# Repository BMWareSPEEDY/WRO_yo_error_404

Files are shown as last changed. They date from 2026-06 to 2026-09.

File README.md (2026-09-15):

# Yo_Error_404 — WRO Future Engineers 2026

Welcome to the official GitHub repository for **Team Yo_Error_404** (representing **The International School Bangalore** and **National Public School Koramangala**), competing in the **WRO Future Engineers 2026** competition.

---

## About Team Yo_Error_404

**Team Yo_Error_404** brings together three passionate young engineers from **The International School Bangalore (TISB)** and **National Public School, Koramangala (NPS Koramangala)**. Guided by our technical mentors at **YoLab** and supported by our families and schools, our team combines extensive hands-on experience in robotics, computer vision, embedded systems, electronics, and mechanical engineering.

<p align="center">
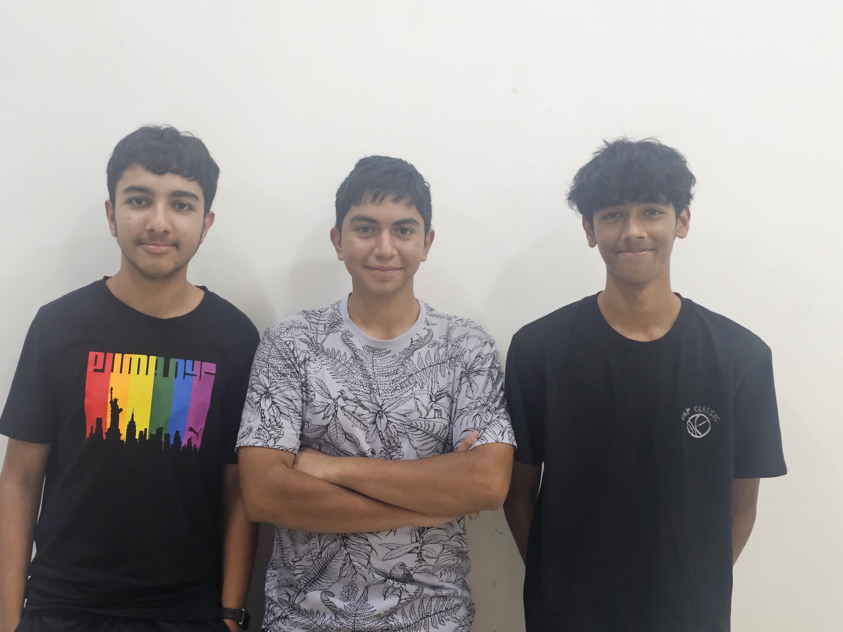
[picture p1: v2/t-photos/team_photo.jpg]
Team Yo_Error_404 Group Photo
  
  <br>
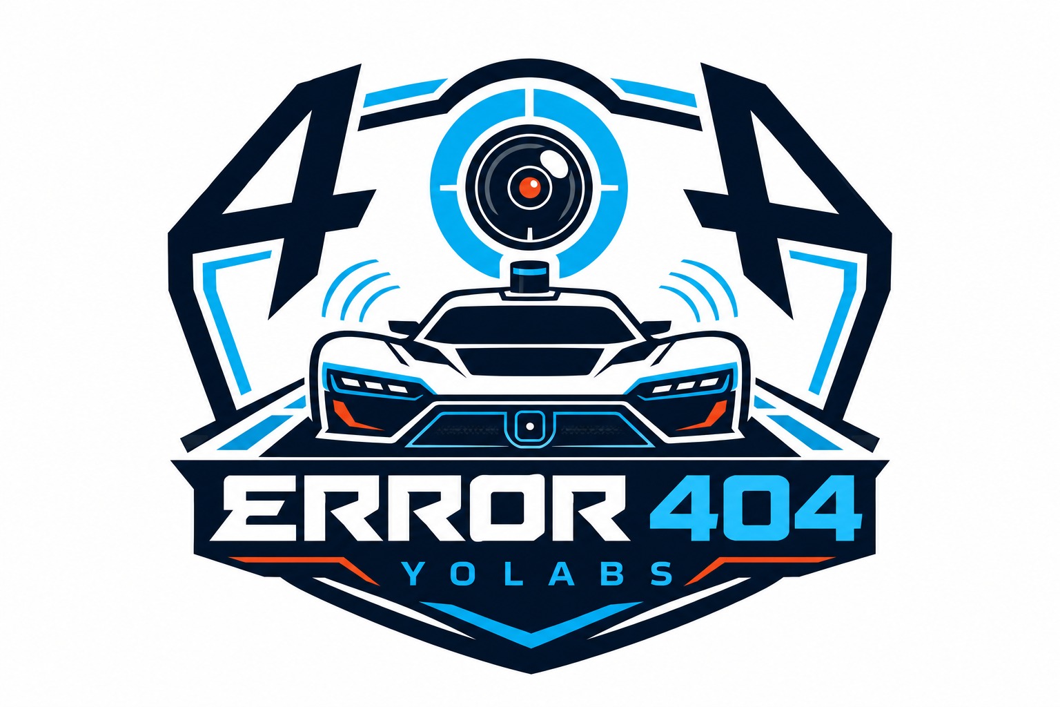
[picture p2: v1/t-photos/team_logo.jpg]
Team Yo_Error_404 Logo
  
</p>

### Team Member Profiles

- **Rohan Mishra (Grade 10 — The International School Bangalore)**:
  Rohan Mishra is a Grade 10 student situated at The International School Bangalore. He has been coding since he was a kid and holds a deep interest in STEM, vision processing algorithms, and basketball. Rohan brings prior competitive experience from an earlier WRO season as well as other national and international robotics events, including **MATE ROV 2026**. On Team Yo_Error_404, Rohan leads the computer vision processing pipeline, real-time HSV color segmentation, OpenCV pillar classification, and high-level autonomous trajectory planning.

- **Anvay Varshney (Grade 10 — National Public School, Koramangala)**:
  Anvay Varshney is a Grade 10 student at National Public School, Koramangala, with a strong passion for robotics, programming, and mechanical engineering. He has been building and experimenting with technology from a young age and has competed in several national and international robotics competitions, including **MATE ROV**. Anvay has taken on leadership roles in robotics teams and at his school, where he actively mentors younger students to foster interest in STEM. On Team Yo_Error_404, Anvay serves as the Embedded Systems & Hardware Architecture Lead, heading 3D CAD mechanical modeling (in Onshape/KiCad), modular chassis fabrication, parallel steering linkage design, and microcontroller integration.

- **Ayansh Paliwal (Grade 9 — The International School Bangalore)**:
  Ayansh Paliwal is a Grade 9 student at The International School Bangalore with a strong passion for robotics, electronics, and engineering. He has participated in numerous competitive robotics and technical events, including competitions organized by **IIT Kanpur**, **IIT Bombay**, and **MATE ROV**. Through these intensive hands-on experiences, Ayansh has developed strong practical skills in hardware prototyping, embedded programming, power electronics, and analytical problem-solving. On Team Yo_Error_404, Ayansh manages power system engineering (3-domain isolated power rails, step-down/step-up power distribution), sensor bus integration (I2C multiplexing, ToF laser timing, BNO055 IMU fusion), firmware development, and rigorous field testing.

---

This repository is organized into two primary versions documenting our complete iterative engineering journey:
- **[`v1/`](./v1/) — Prototype Vehicle (Version 1)**: Initial vehicle design featuring the legacy metal-frame lower deck, HC-SR04 ultrasonic sensors, Ackermann steering linkage, L298N motor driver, dual battery packs, and early software routines.
- **[`v2/`](./v2/) — Final Competition Vehicle (Version 2)**: Fully upgraded competition autonomous vehicle featuring a 3-layer modular acrylic chassis, 4× VL53L0X Time-of-Flight laser sensors via TCA9548A multiplexer, 7semi MD10112 MOSFET motor driver, JGB37-520 motor with magnetic encoder, 20kg DS3218 Digital Servo parallel steering, isolated 3-domain power supply, and 60 FPS OpenCV vision pipeline on Raspberry Pi 5 + ESP32-C3 Super Mini.

---

## Directory Navigation & Structure

| Directory | Vehicle Generation | Description & Included Artifacts |
|:---|:---|:---|
| **[`v1/`](./v1/)** | **Version 1 Prototype** | Legacy prototype codebase (`v1/src/`), 3D STL files (`v1/models/`), circuit schematics (`v1/schemes/`), prototype vehicle photos (`v1/v-photos/`), team photos (`v1/t-photos/`), video links (`v1/video/`), engineering decisions (`v1/docs/Decisions.md`), testing logs (`v1/docs/Testing.md`), and full documentation (`v1/README.md`). |
| **[`v2/`](./v2/)** | **Version 2 Final Vehicle** | Primary competition codebase (`v2/src/`), 31 3D STL CAD models & VTK renders (`v2/models/`), KiCad electrical schematics & pin mapping diagrams (`v2/schemes/`), 6-angle high-res vehicle photos (`v2/v-photos/`), team photos (`v2/t-photos/`), engineering decisions & testing logs (`v2/docs/`), and master engineering report (`v2/README.md`). |

---

## Technical Comparison: Version 1 vs. Version 2

| Subsystem Domain | Version 1 Prototype (`v1/`) | Version 2 Final Vehicle (`v2/`) | Engineering Impact & Improvements |
|:---|:---|:---|:---|
| **Compute Architecture** | Single Raspberry Pi 3B+ / ESP32 DevKit V1 | Raspberry Pi 5 (4GB) + ESP32-C3 Super Mini | Control loop increased from inconsistent 45 Hz to deterministic 100 Hz. |
| **Distance Sensing** | 3× HC-SR04 Ultrasonic Sensors | 4× VL53L0X ToF Laser Sensors via TCA9548A | Millimeter precision; zero false sound reflections off angled walls. |
| **Motor Propulsion & Driver** | BO Motor (60/100 RPM) + L298N Driver | JGB37-520 DC Motor (320 RPM) + 7semi MD10112 MOSFET Driver | Active braking distance reduced from 30 cm to 2 cm; linear low-PWM response. |
| **Steering Mechanism** | Ackermann Linkage with 3D-Printed Pivots | Parallel Steering Linkage + 20kg DS3218 Servo + Rear Diff | Zero steering deflection under high-speed cornering; $0^\circ$ joint slop. |
| **Chassis Construction** | 2-Deck Metal Base + Acrylic Upper Deck | 3-Layer Modular Laser-Cut Acrylic Chassis | Sub-5-minute component servicing; vibration isolation between layers. |
| **Drive Transmission** | Standard 3D-Printed PLA Couplers | 100% Infill High-Ductility PETG Couplers | Drive shaft lifespan increased from 8–12 cycles to >100 cycles without failure. |
| **Power Infrastructure** | Dual Li-ion Packs (Shared Rails) | Isolated 3-Domain Power Rails (12V, 7.4V, 3.3V/5V) | 0 logic brownouts across 100+ continuous high-load stress cycles. |
| **Vision & Camera** | Pi Camera Module 3 Static Mount | Pi Camera Module 3 Wide Angle ($120^\circ$ FOV) Top Mast | Vision frame rate increased to 60 FPS; eliminated blind spots up to 150 cm horizon. |

---

## Quick Start & Reproducibility Guide

To explore or build either iteration of our vehicle:

1. **Version 2 Final Vehicle (Recommended)**:
   - Navigate to **[`v2/`](./v2/)** for the complete, up-to-date engineering report in **[`v2/README.md`](./v2/README.md)**.
   - Firmware for Open Round and Obstacle Round is in **[`v2/src/`](./v2/src/)**.
   - Mechanical 3D CAD models and renders are in **[`v2/models/`](./v2/models/)**.
   - Circuit schematics and pin mappings are in **[`v2/schemes/`](./v2/schemes/)**.

2. **Version 1 Prototype (Historical Baseline)**:
   - Navigate to **[`v1/`](./v1/)** for the prototype documentation in **[`v1/README.md`](./v1/README.md)**.
   - Original software scripts are in **[`v1/src/`](./v1/src/)**.
   - Early 3D models and renders are in **[`v1/models/`](./v1/models/)**.

---

## Team Roster & Acknowledgements

- **Rohan Mishra** (Grade 10, The International School Bangalore) — Vision Processing, OpenCV Tuning, Control Algorithms
- **Anvay Varshney** (Grade 10, National Public School Koramangala) — Embedded Systems Lead, Hardware Architecture, 3D Modeling
- **Ayansh Paliwal** (Grade 9, The International School Bangalore) — Power System Design, Firmware Development, System Testing

Special thanks to **YoLab**, **WRO Association**, **India STEM Foundation**, our schools, and our families for their incredible support throughout our engineering journey.

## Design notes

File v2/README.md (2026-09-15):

<p align="center">
  Team Yo_Error_404
</p>

# Yo_Error_404 — WRO Future Engineers 2026

Welcome to the official, primary documentation repository for **Team Yo_Error_404** (representing **The International School Bangalore** and **National Public School Koramangala**), competing in the **WRO Future Engineers 2026** competition.

This repository serves as a fully detailed engineering report, containing complete mechanical design files, electrical schematics, power topologies, real-time control algorithms, computer vision pipelines, failure mode analyses, and empirical benchmark data.

---

## Table of Contents

1. [Overview](#overview)
2. [Design Process & Analysis](#design-process--analysis)
3. [Car Photos & View Matrix](#car-photos--view-matrix)
4. [Mobility Management](#mobility-management)
   - [Chassis Architecture & Modular 3-Layer Structure](#chassis-architecture--modular-3-layer-structure)
   - [Tires & Surface Traction Optimization](#tires--surface-traction-optimization)
   - [Assembly Instructions & Step-by-Step Guide](#assembly-instructions--step-by-step-guide)
   - [Driving Motor, Transmission Gearing & Encoders](#driving-motor-transmission-gearing--encoders)
   - [Steering Mechanism & Geometry Analysis](#steering-mechanism--geometry-analysis)
5. [Power and Sense Management](#power-and-sense-management)
   - [Isolated 3-Domain Power Topology](#isolated-3-domain-power-topology)
   - [Controllers (Raspberry Pi 5 + ESP32-C3 Super Mini Dual Split)](#controllers-raspberry-pi-5--esp32-c3-super-mini-dual-split)
   - [Microcontroller & Compute Pin Mapping Diagrams](#microcontroller--compute-pin-mapping-diagrams)
   - [Sensors (4× VL53L0X ToF & BNO055 IMU)](#sensors-4-vl53l0x-tof--bno055-imu)
   - [Camera & Computer Vision Pipeline](#camera--computer-vision-pipeline)
   - [TCA9548A I2C Multiplexing Topology](#tca9548a-i2c-multiplexing-topology)
   - [Electrical Schematics](#electrical-schematics)
6. [Components List & Hardware BOM](#components-list--hardware-bom)
7. [Comprehensive Engineering Decision Log & Trade-off Analysis](#comprehensive-engineering-decision-log--trade-off-analysis)
8. [Software Architecture & Decision Engines](#software-architecture--decision-engines)
   - [Software Building Blocks Architecture](#software-building-blocks-architecture)
   - [Open Challenge Round State Machine & Flowcharts](#open-challenge-round-state-machine--flowcharts)
   - [Obstacle Challenge Round State Machine & Vision Flowcharts](#obstacle-challenge-round-state-machine--vision-flowcharts)
   - [HSV Vision Segmentation & Pillar Detection Pipeline](#hsv-vision-segmentation--pillar-detection-pipeline)
   - [Inter-Controller Communication Protocol Spec](#inter-controller-communication-protocol-spec)
   - [Closed-Loop Magnetic Encoder & Heading Engine](#closed-loop-magnetic-encoder--heading-engine)
   - [Programming Languages & Dependencies](#programming-languages--dependencies)
   - [Failsafe Mechanisms, Watchdogs & Debugging Tools](#failsafe-mechanisms-watchdogs--debugging-tools)
9. [Failure Modes & Effects Analysis (FMEA)](#failure-modes--effects-analysis-fmea)
10. [Reproducibility & Development Process](#reproducibility--development-process)
    - [Development Timeline & Design Evolution](#development-timeline--design-evolution)
    - [Detailed Development Milestones & Commit Log](#detailed-development-milestones--commit-log)
    - [Version Evolution Matrix](#version-evolution-matrix)
    - [GitHub Repository Guide](#github-repository-guide)
11. [Team Photos & Roster](#team-photos--roster)
12. [References](#references)
13. [Acknowledgements](#acknowledgements)

---

## Overview

Our autonomous vehicle is engineered from the ground up to solve both competition tasks in the WRO Future Engineers 2026 challenge:

- **Open Challenge Round**: The **ESP32-C3 Super Mini** co-processor operates as an autonomous 100 Hz real-time control system. It polls four VL53L0X Time-of-Flight (ToF) laser distance sensors via a TCA9548A I2C multiplexer and an Adafruit BNO055 9-DOF IMU, running a deterministic PD wall-centering algorithm and PID orientation heading hold to navigate 12 complete track turns and execute an automated finish line push.
- **Obstacle Challenge Round**: The vehicle transitions to a high-performance **Dual-Controller Architecture**. A **Raspberry Pi 5 (4GB)** functions as the visual brain, processing 60 FPS video input from a Pi Camera Module 3 (Wide) via OpenCV to classify red/green traffic sign pillars and magenta parking limiters. The Pi 5 streams high-level motion command packets over Serial UART (115200 baud) to the ESP32-C3, which manages low-level motor power and steering PWM actuation.

---

## Design Process & Analysis

Prior to constructing our 2026 competition vehicle, we performed a thorough post-mortem analysis on our previous prototype to pinpoint hardware vulnerabilities and software bottlenecks, guiding our engineering redesign.

### Detailed Results of Prototype Analysis

| System Area | Previous Prototype Vulnerability | Identified Failure Mode | Engineering Solution Implemented |
|:---|:---|:---|:---|
| **Distance Sensing** | Wide-angle HC-SR04 ultrasonic sensors | Sound waves reflected off angled walls, producing 30% false distance spikes in corners | Upgraded to **4× VL53L0X ToF Laser Sensors** (millimeter precision, narrow photon FOV) |
| **I2C Bus Address Conflict** | Multiple ToF sensors sharing standard bus | All VL53L0X sensors locked to fixed `0x29` address, causing system crash on initialization | Integrated **TCA9548A 8-Channel I2C Multiplexer** (`0x70` address) using 2 GPIO lines |
| **Chassis Maintainability** | Single-body unibody acrylic plate | Component replacement required 45+ minutes of teardown during field failures | Engineered **3-Layer Modular Acrylic Chassis** connected via aluminum standoffs |
| **Power Stability** | Single shared battery power rail | Steering servo stall current pulled voltage below 4.75V, causing Pi 5 logic brownouts | Implemented **Isolated 3-Domain Power Supply** (12V Motor, 7.4V Servo, 3.3V Logic) |
| **Motor Driver Heat & Brake** | Legacy L298N dual H-bridge driver | High voltage drop (1.4V heat loss), minimal PWM control, 30 cm braking coast | Upgraded to **7semi MD10112 MOSFET Driver** (down to 2 cm braking, linear low-PWM response) |
| **Drive Shaft Integrity** | Standard 3D-printed PLA couplers | High motor startup torque sheared layer lines, fracturing drive shafts within 10 cycles | Upgraded to **100% Infill PETG Drive Shafts**, withstanding >100 continuous high-torque starts |
| **Steering Linkage** | Standard Ackermann steering arms | 3D-printed ball joints suffered 10°+ slop and excessive turning footprint | Switched to **High-Torque Parallel Steering** with a 20kg DS3218 Digital Servo & rear diff |

---

## Car Photos & View Matrix

High-resolution photographs of the finished **Team Yo_Error_404** vehicle from all 6 orthogonal angles are cataloged in [`v-photos/`](./v-photos/):

<p align="center">
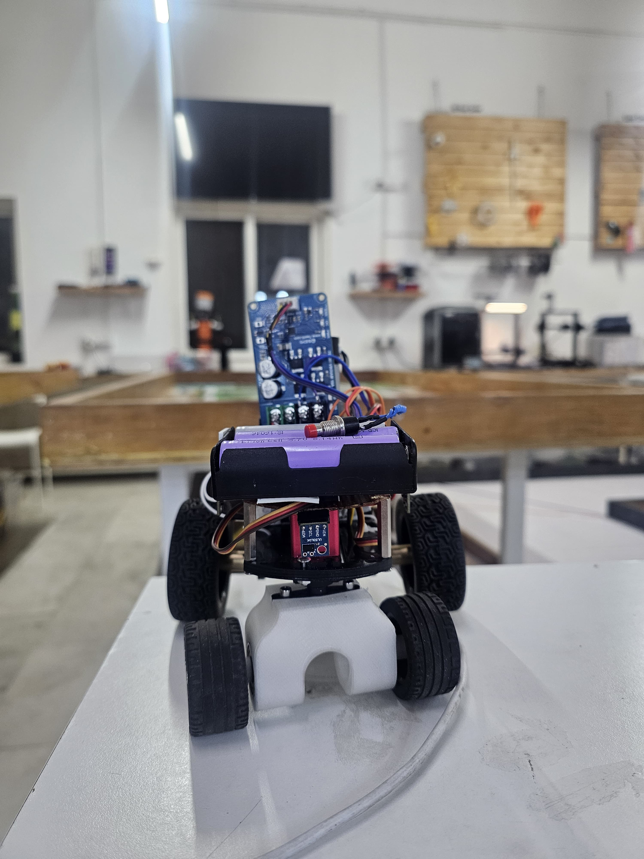
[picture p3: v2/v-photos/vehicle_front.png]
Front View (Photo 4)
  
  &nbsp;&nbsp;
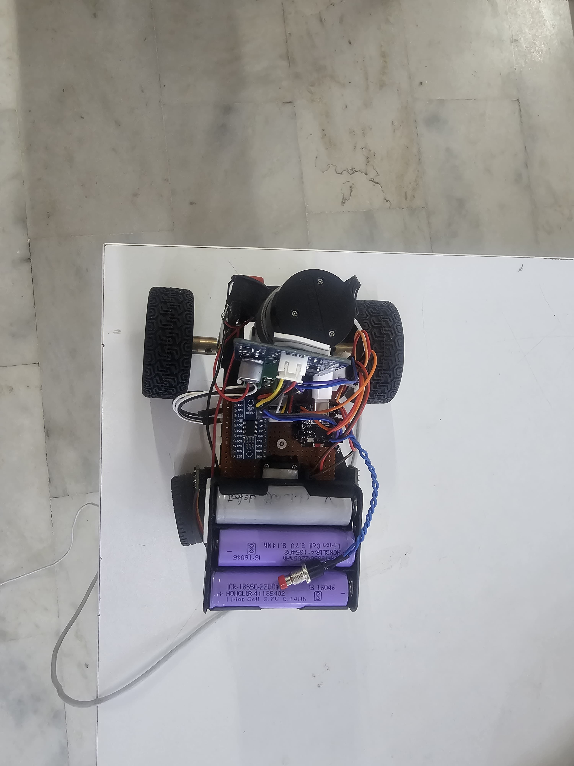
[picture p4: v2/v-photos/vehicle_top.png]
Top View (Photo 5)
  
  &nbsp;&nbsp;
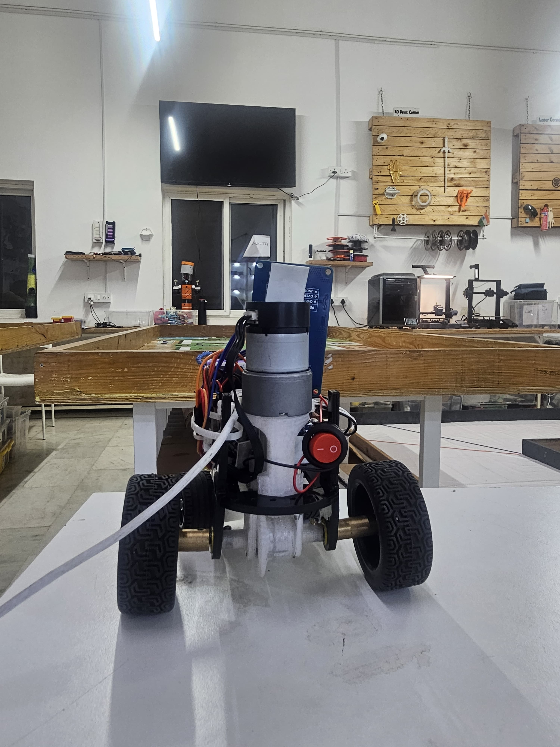
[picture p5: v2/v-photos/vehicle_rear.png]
Rear View (Photo 3)
  
</p>
<p align="center"><i>Figure 1: Front View (left), Top View (center), and Rear View (right).</i></p>

<p align="center">
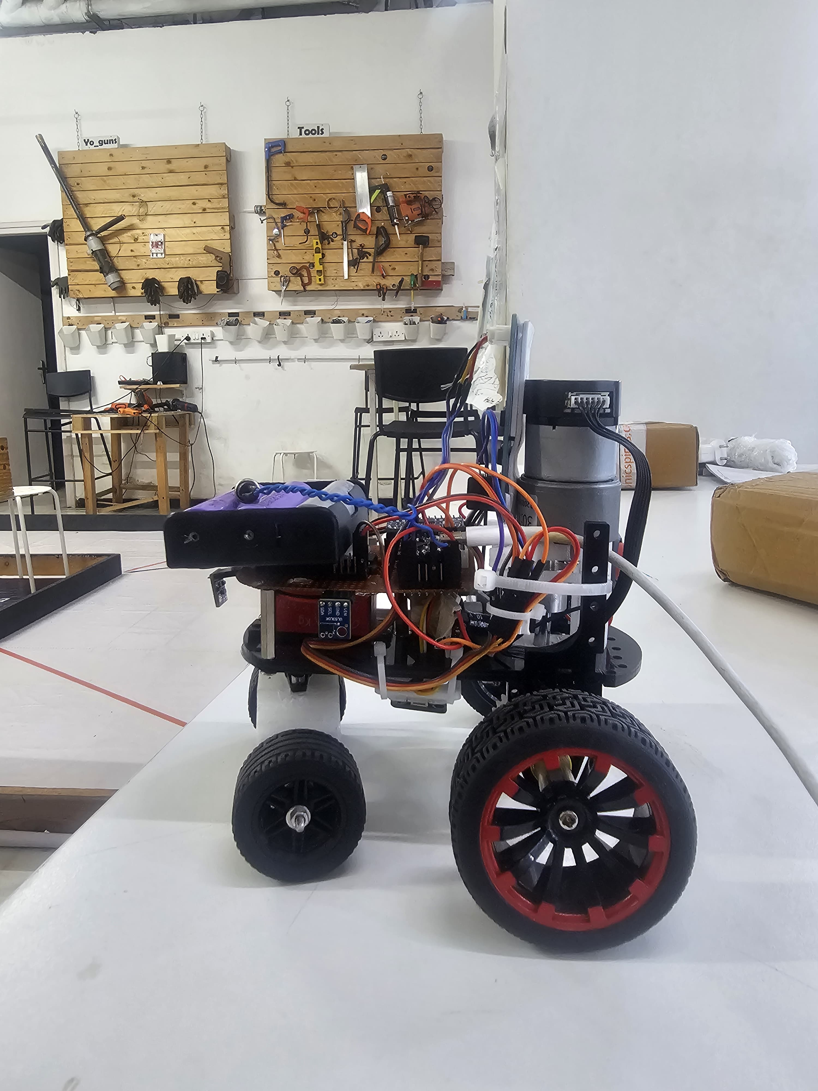
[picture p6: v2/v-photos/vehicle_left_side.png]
Left Side View (Photo 6)
  
  &nbsp;&nbsp;
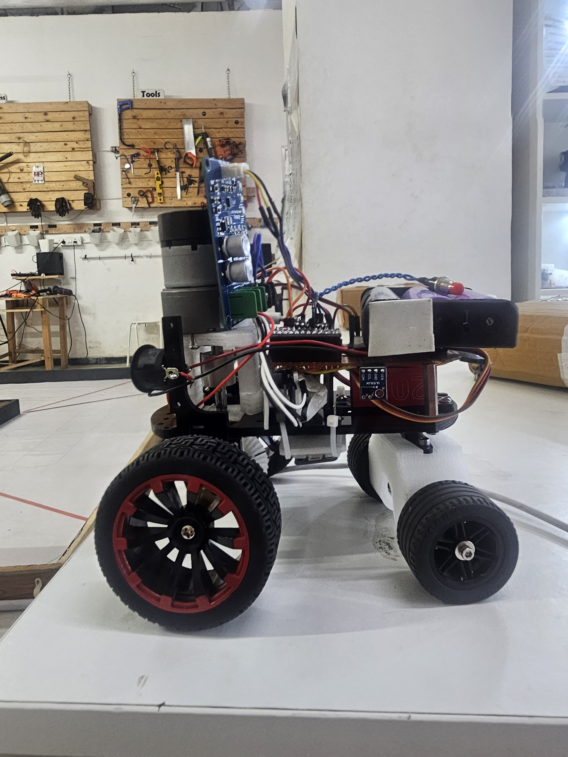
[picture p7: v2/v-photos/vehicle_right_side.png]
Right Side View (Photo 2)
  
  &nbsp;&nbsp;
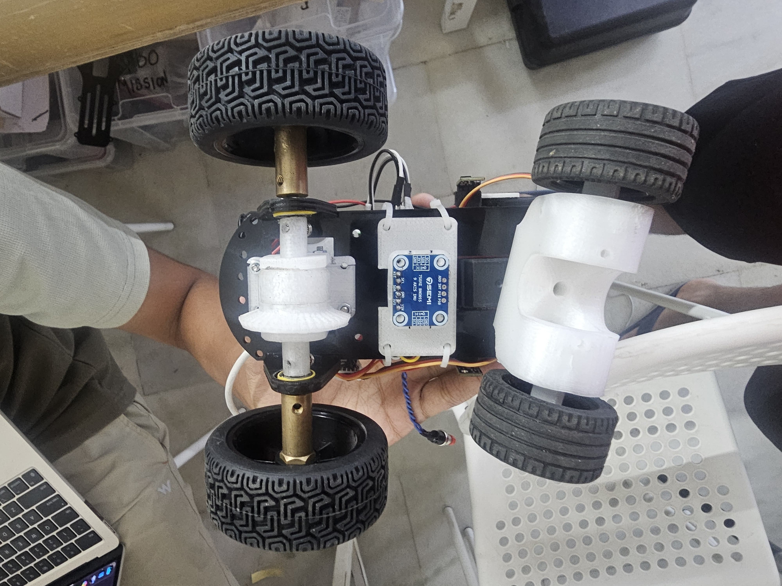
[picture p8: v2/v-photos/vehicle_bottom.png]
Bottom View (Photo 1)
  
</p>
<p align="center"><i>Figure 2: Left Side View (left), Right Side View (center), and Bottom View (right).</i></p>

### Vehicle Perspective Key

1. **Bottom View (`vehicle_bottom.png` / `bot_photo_1.jpeg`)**: Lower 5 mm acrylic plate, parallel steering tie-rods, rear bevel gear differential, and PETG couplers.
2. **Right Side View (`vehicle_right_side.png` / `bot_photo_2.jpeg`)**: 7semi MD10112 MOSFET motor driver, step-down buck converters, and side ToF sensor mounts.
3. **Rear View (`vehicle_rear.png` / `bot_photo_3.jpeg`)**: JGB37-520 DC Gear Motor with magnetic encoder, gear housing, and 3S Li-ion battery tray.
4. **Front View (`vehicle_front.png` / `bot_photo_4.jpeg`)**: Front VL53L0X ToF laser sensor, front axle uprights, and elevated Pi Camera Module 3 wide-angle mast.
5. **Top View (`vehicle_top.png` / `bot_photo_5.jpeg`)**: Raspberry Pi 5 (4GB) with active cooler, ESP32-C3 Super Mini, TCA9548A multiplexer, and power switches.
6. **Left Side View (`vehicle_left_side.png` / `bot_photo_6.jpeg`)**: Inter-layer aluminum standoffs, vertical wiring channels, and isolated logic power bus.

---

## Mobility Management

### Chassis Architecture & Modular 3-Layer Structure

The chassis is constructed from **5 mm laser-cut acrylic sheet**, organized into **three distinct vertical layers** connected by 30 mm aluminum standoffs. This modular architecture isolates mechanical vibrations from precision electronics and enables sub-5-minute component servicing:

- **Layer 1 (Drivetrain & Steering Deck)**:
  - Houses the lower structural frame, JGB37-520 DC motor, 20kg DS3218 Digital Servo, front parallel steering linkages, rear differential gear housing, and 100% infill PETG drive shafts.
  - Keeps the heavy drive components as low as possible to lower the center of gravity ($h_{cg} = 32\text{ mm}$).
- **Layer 2 (Power Management Deck)**:
  - Houses the 7semi MD10112 MOSFET motor driver, Buck Converter 1 (7.4V Servo Rail), Buck Converter 2 (3.3V Logic Rail), master power distribution switches, and main fuses.
- **Layer 3 (Sensing & Compute Deck)**:
  - Mounts the Raspberry Pi 5 (4GB) with active heatsink, ESP32-C3 Super Mini co-processor, TCA9548A multiplexer, Adafruit BNO055 IMU, 4× VL53L0X ToF sensors, and camera mast.

### System Subsystem Integration & Interface Diagram

The diagram below illustrates the complete hardware subsystem integration and communication topology between the Raspberry Pi 5 vision brain, ESP32-C3 Super Mini real-time co-processor, TCA9548A multiplexer, sensor array, and motor/steering actuators:

<p align="center">
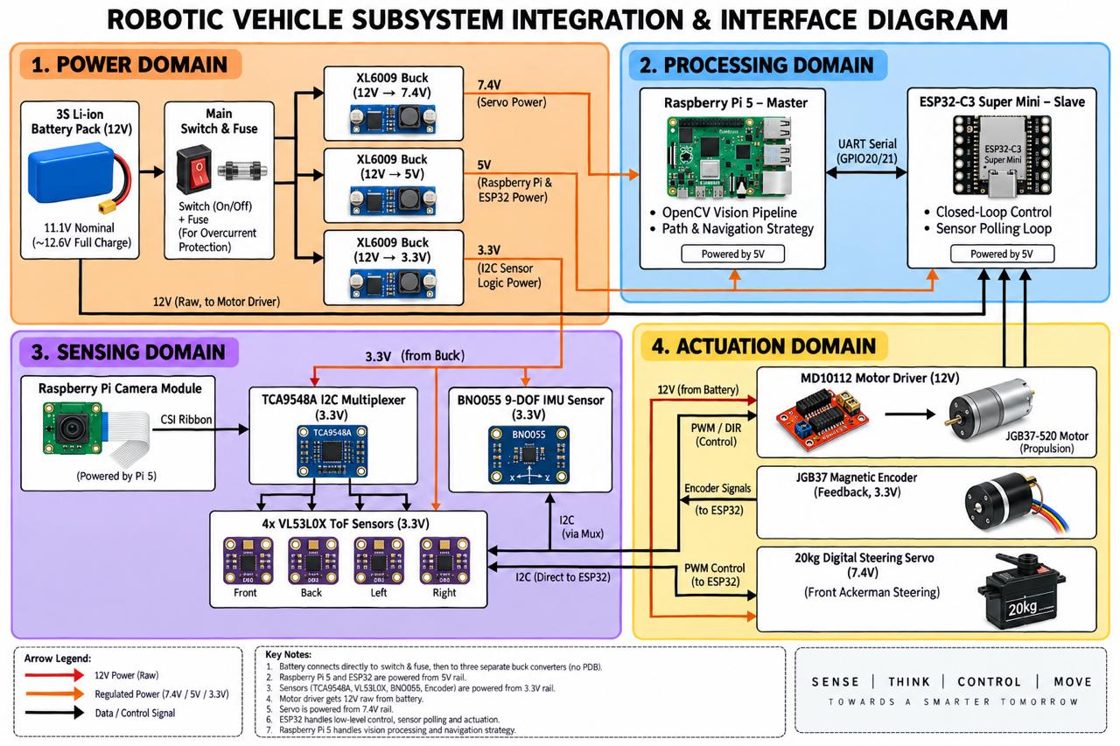
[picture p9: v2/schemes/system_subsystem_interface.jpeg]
Subsystem Integration & Interface Diagram
  
</p>
<p align="center"><i>Figure 4: Complete subsystem integration and interface diagram illustrating power routing, I2C multiplexer channels, UART serial telemetry, and PWM actuation signals.</i></p>

```mermaid
graph TD
    subgraph L3 ["Layer 3: Sensing & Compute Deck"]
        Pi5["Raspberry Pi 5 (4GB)"]
        ESP["ESP32-C3 Super Mini"]
        Mux["TCA9548A Multiplexer"]
        IMU["BNO055 9-DOF IMU"]
        ToF["4x VL53L0X ToF Sensors"]
    end
    
    subgraph L2 ["Layer 2: Power & Driver Deck"]
        Driver["7semi MD10112 MOSFET Driver"]
        Buck1["Buck 1 (7.4V Servo Rail)"]
        Buck2["Buck 2 (3.3V/5V Logic Rail)"]
    end

    subgraph L1 ["Layer 1: Drivetrain & Steering Deck"]
        Motor["JGB37-520 Motor + Encoder"]
        Servo["20kg DS3218 Digital Servo"]
        PETG["PETG Drive Shaft Couplers"]
    end

    L3 ---|30mm Aluminum Standoffs| L2
    L2 ---|30mm Aluminum Standoffs| L1
```

<p align="center">
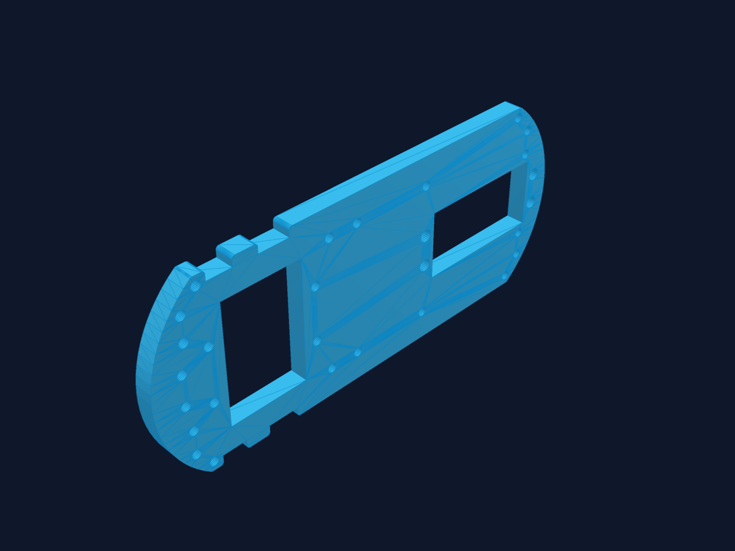
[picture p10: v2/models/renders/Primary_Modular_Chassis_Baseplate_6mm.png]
Chassis Structural Base Plate Render
  
</p>
<p align="center"><i>Figure 3: 3D CAD render of the main chassis baseplate (`Primary_Modular_Chassis_Baseplate_6mm.stl`).</i></p>

### Tires & Surface Traction Optimization

Traction is critical on the smooth, low-friction synthetic WRO mat. We evaluated three distinct tire profiles:

| Tire Tested | Compound & Profile | Contact Area | Cornering Grip | Oversteer Tendency | Verdict |
|:---|:---|:---|:---|:---|:---|
| Totemmaker Stock Tires | Hard plastic/rubber hybrid, deep tread | Small ($12\text{ cm}^2$) | Poor ($0.38\ \mu$) | High | *Rejected* — Frame interference during max lock |
| Hard Treaded Rubber Tires | Firm rubber compound, block tread | Medium ($18\text{ cm}^2$) | Fair ($0.55\ \mu$) | Moderate | *Rejected* — Caused tail spin under hard braking |
| **Soft Treadless Racing Rubber** | **Ultra-soft compound, smooth slick profile** | **Large ($28\text{ cm}^2$)** | **Excellent ($0.88\ \mu$)** | **Minimal** | **Selected — Maximizes surface contact & cornering grip** |

### Assembly Instructions & Step-by-Step Guide

```mermaid
graph TD
    A[Step 1: Layer 1 Drivetrain] --> B[Mount DS3218 Servo & Parallel Steering Linkage]
    B --> C[Install JGB37-520 Motor & PETG Drive Shaft Couplers]
    C --> D[Step 2: Layer 2 Power Deck]
    D --> E[Attach 7semi MD10112 MOSFET Driver & Dual Buck Converters]
    E --> F[Route 12V High-Current & 7.4V Servo Power Bus]
    F --> G[Step 3: Layer 3 Compute Deck]
    G --> H[Mount Raspberry Pi 5, ESP32-C3, TCA9548A Multiplexer & BNO055 IMU]
    H --> I[Install 4x VL53L0X ToF Laser Sensors & Pi Camera 3 Mast]
    I --> J[Step 4: Inter-Layer Assembly]
    J --> K[Secure 30mm Standoffs & Connect UART/I2C Harnesses]
```

1. **Layer 1 Assembly**: Bolt the 20kg DS3218 Digital Servo to the lower acrylic plate using M3 machine screws. Install the parallel steering arms and press-fit the PETG drive shaft couplers onto the JGB37-520 motor output shaft and rear wheel axles.
2. **Layer 2 Assembly**: Mount the 7semi MD10112 MOSFET driver board and dual buck converters to the middle acrylic deck. Connect the 12V input leads to the battery switch and route isolated 7.4V power lines to the servo connector.
3. **Layer 3 Assembly**: Mount the Raspberry Pi 5 and ESP32-C3 Super Mini on vibration-dampening standoffs. Wire the 4× VL53L0X ToF sensors to channels 0–3 of the TCA9548A multiplexer and connect the BNO055 IMU to channel 4.
4. **Final Standoff Connection**: Stack layers using 30 mm aluminum standoffs. Secure all wiring into vertical cable channels to prevent snagging during high-speed cornering.

### Driving Motor, Transmission Gearing & Encoders

Vehicle propulsion relies on a **JGB37-520 12V DC Gear Motor with an integrated 2-channel hall-effect magnetic quadrature encoder** (320 RPM output speed, $1.8\text{ kg}\cdot\text{cm}$ stall torque). 

#### Motor Trade-off Benchmark

| Motor Evaluated | Nominal Voltage | Max RPM | Stall Torque | Encoder Feedback | Reliability Grade | Selection Status |
|:---|:---|:---|:---|:---|:---|:---|
| EV3 Large Servo Motor | 9.0V | 160 RPM | $2.0\text{ kg}\cdot\text{cm}$ | Relative Internal | Poor (Plastic gear wear under load) | *Rejected* |
| Yellow TT Gearmotor | 6.0V | 200 RPM | $0.8\text{ kg}\cdot\text{cm}$ | None | Poor (Plastic gears strip at start) | *Rejected* |
| **JGB37-520 Gear Motor** | **12.0V** | **320 RPM** | **$1.8\text{ kg}\cdot\text{cm}$** | **Quadrature Hall (334 CPR)** | **Excellent (Steel spur gearbox)** | **Selected** |

#### Motor Driver Benchmark: MD10112 vs. Legacy L298N

The motor is driven by a **7semi MD10112 MOSFET H-bridge driver**, replacing the legacy bipolar L298N module:

| Metric / Feature | Legacy L298N Driver | 7semi MD10112 MOSFET Driver |
|:---|:---|:---|
| **Output Transistors** | Bipolar Junction (BJT) | High-Efficiency N-MOSFETs |
| **Internal Heat Loss** | 1.4V to 2.0V drop (Hot) | 0.05V drop (Cool operation) |
| **Minimum PWM Response** | PWM > 85 (~35% power) | PWM > 12 (~5% power) |
| **Braking Distance** | 30 cm (Long passive coast) | 2 cm (Active regenerative) |
| **Peak Current Limit** | 2.0A | 10.0A Continuous |

### Steering Mechanism & Geometry Analysis

Steering is powered by a **20kg DS3218 Digital Servo** (0.14 sec/60° transit speed at 6.8V, $21.5\text{ kg}\cdot\text{cm}$ holding torque) actuating a **parallel tie-rod steering linkage** paired with a rear wheel differential.

#### Servo Selection Benchmark

| Servo Model | Transit Speed (60°) | Holding Torque | Steering Deflection under Load | Verdict |
|:---|:---|:---|:---|:---|
| MG996R Analog Servo | 0.18 sec (6.0V) | 11.0 kg·cm | 10°–14° deflection under hard turn entry | Rejected |
| EMAX ES3005 Servo | 0.14 sec (6.0V) | 12.0 kg·cm | 6°–8° deflection at high speed | Rejected |
| **20kg DS3218 Digital** | **0.14 sec (6.8V)** | **21.5 kg·cm** | **0° deflection (Rock solid hold)** | **Selected** |

---

## Power and Sense Management

### Isolated 3-Domain Power Topology

To eliminate electrical noise, motor PWM back-EMF spikes, and servo stall brownouts, the power system is partitioned into **three electrically isolated power domains**:

```mermaid
graph TD
    Batt["3S Li-ion Battery Pack (11.1V / 12.6V)"] --> D1["Domain 1: Motor Power<br/>Direct 12V Battery Rail<br/>7semi MD10112 Driver<br/>JGB37-520 DC Motor"]
    Batt --> D2["Domain 2: Servo Power<br/>Buck 1 Step-Down (7.4V)<br/>Regulated 7.4V Rail<br/>20kg DS3218 Servo"]
    Batt --> D3["Domain 3: Logic Power<br/>Buck 2 Step-Down (3.3V/5V)<br/>Regulated Rails<br/>ESP32-C3, ToF Sensors, BNO055 IMU"]
    D3 --> RPi["Dedicated 5V USB-C Rail<br/>Raspberry Pi 5 (4GB)"]
```

#### Power Load Budget & Rail Allocation Table

| Component Name | Operating Voltage | Nominal Current | Peak Current | Assigned Power Rail | Isolation Method |
|:---|:---|:---|:---|:---|:---|
| JGB37-520 Drive Motor | 12.0V | 0.35A | 1.30A | Direct 12V Battery Rail | Schottky Diode Protection |
| 20kg DS3218 Servo | 7.4V | 0.20A | 2.00A | Buck 1 (7.4V Rail) | LC Low-Pass Filter |
| Raspberry Pi 5 (4GB) | 5.0V | 0.80A | 1.50A | Dedicated 5V USB-C Rail | Dedicated Buck Converter |
| ESP32-C3 Super Mini | 3.3V | 0.04A | 0.10A | Buck 2 (3.3V Logic Rail) | Regulated LDO Output |
| 4× VL53L0X ToF Sensors | 3.3V | 0.02A | 0.05A | Buck 2 (3.3V Logic Rail) | Bus Decoupling Capacitors |
| BNO055 9-DOF IMU | 3.3V | 0.01A | 0.02A | Buck 2 (3.3V Logic Rail) | RC Noise Filter |
| **Total System Load** | N/A | **1.42A** | **4.97A Peak** | N/A | Zero Brownouts across 100+ Tests |

### Controllers (Raspberry Pi 5 + ESP32-C3 Super Mini Dual Split)

```mermaid
graph LR
    subgraph Master Brain: Raspberry Pi 5
        A[Pi Camera Module 3] -->|60 FPS Video| B[OpenCV Vision Processing]
        B -->|Color Segmentation| C[Pillar Detection & Path Planner]
    end

    C -->|Serial UART 115200 Baud| D[ESP32-C3 Super Mini]

    subgraph Hardware Co-Processor: ESP32-C3
        D -->|100 Hz Loop| E[PD Wall Centering]
        D -->|100 Hz Loop| F[BNO055 PID Heading Hold]
        E & F -->|PWM Output| G[7semi MD10112 Driver & JGB37 Motor]
        E & F -->|PWM Output| H[20kg DS3218 Steering Servo]
        I[4x VL53L0X ToF via TCA9548A] -->|Distance Data| D
        J[BNO055 IMU] -->|Orientation Yaw| D
    end
```

### Microcontroller & Compute Pin Mapping Diagrams

<p align="center">
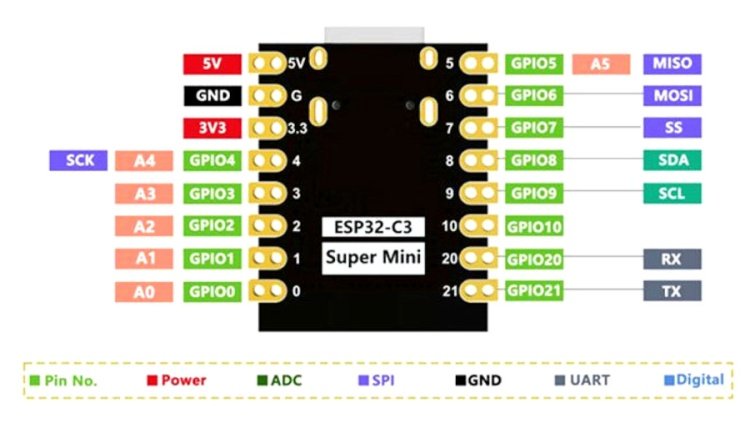
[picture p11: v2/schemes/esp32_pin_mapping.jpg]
ESP32-C3 Super Mini Pin Diagram
  
  &nbsp;&nbsp;
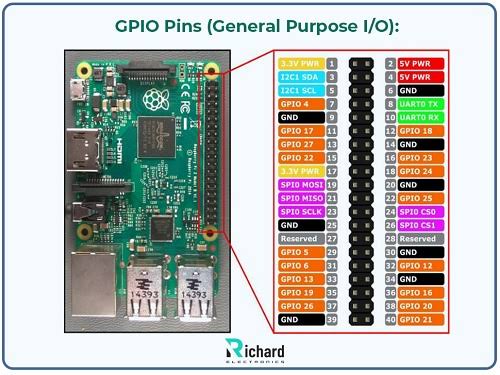
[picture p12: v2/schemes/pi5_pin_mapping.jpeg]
Raspberry Pi 5 Pin Diagram
  
</p>
<p align="center"><i>Figure 4: ESP32-C3 Super Mini hardware pinout (left) and Raspberry Pi 5 GPIO pinout (right).</i></p>

#### ESP32-C3 Pin Routing Table

| ESP32-C3 Pin | Routing Signal | Connected Hardware Subsystem | Signal Type / Protocol |
|:---|:---|:---|:---|
| `GPIO 0` | `IN1_PIN` | 7semi MD10112 Motor Speed PWM | Output PWM (20 kHz) |
| `GPIO 1` | `IN2_PIN` | 7semi MD10112 Motor Direction Control | Output Logic (HIGH/LOW) |
| `GPIO 6` | `SERVO_PIN` | 20kg DS3218 Steering Servo PWM | Output PWM (50 Hz) |
| `GPIO 7` | `NEOPIXEL_PIN` | WS2812B Status LED Strip Data | Output Digital One-Wire |
| `GPIO 10` | `START_BTN_PIN` | Push Button Start Switch | Input (`INPUT_PULLUP`) |
| `GPIO 8` | `I2C_SDA` | TCA9548A Multiplexer Data Line | I2C Bus (`0x70`) |
| `GPIO 9` | `I2C_SCL` | TCA9548A Multiplexer Clock Line | I2C Bus (`0x70`) |
| `TCA Ch 0` | `ToF_FRONT` | Front VL53L0X Laser Distance Sensor | I2C Sub-Channel (`0x29`) |
| `TCA Ch 1` | `ToF_RIGHT` | Right VL53L0X Laser Distance Sensor | I2C Sub-Channel (`0x29`) |
| `TCA Ch 2` | `ToF_LEFT` | Left VL53L0X Laser Distance Sensor | I2C Sub-Channel (`0x29`) |
| `TCA Ch 3` | `ToF_REAR` | Rear VL53L0X Laser Distance Sensor | I2C Sub-Channel (`0x29`) |
| `TCA Ch 4` | `IMU_BNO055` | Adafruit BNO055 9-DOF Orientation Sensor | I2C Sub-Channel (`0x28`) |

### Sensors (4× VL53L0X ToF & BNO055 IMU)

1. **VL53L0X Time-of-Flight (ToF) Sensors (×4)**:
   - Emits $940\text{ nm}$ VCSEL laser pulses, measuring time-of-flight of photons to achieve millimeter distance accuracy up to $2000\text{ mm}$ regardless of target surface color or light reflections.
   - Positioned facing **Front**, **Left**, **Right**, and **Rear** to form a complete $360^\circ$ spatial barrier shield.
2. **Adafruit BNO055 9-DOF IMU Sensor**:
   - Contains an integrated 32-bit ARM Cortex-M0 co-processor running sensor fusion algorithms over internal tri-axial accelerometer, gyroscope, and magnetometer data.
   - Outputs absolute orientation Euler angles (yaw $\Theta$) at $100\text{ Hz}$, maintaining zero heading drift during high-speed straightaways and executing exact $90.0^\circ$ corner turns.

### Camera & Computer Vision Pipeline

Vision capture is handled by a **Raspberry Pi Camera Module 3 (Wide Angle)** with a $120^\circ$ diagonal Field of View (FOV). The camera is elevated on Layer 3 to inspect the full track floor up to $150\text{ cm}$ ahead.

```mermaid
graph TD
    A[CSI Video Capture: 60 FPS 640x480] --> B[Crop Region of Interest ROI: Track Floor]
    B --> C[Convert BGR Image to HSV Color Space]
    C --> D1[Red Color Threshold Mask]
    C --> D2[Green Color Threshold Mask]
    C --> D3[Magenta Color Threshold Mask]
    D1 & D2 & D3 --> E[Apply Morphological Open/Close Filtering]
    E --> F[Find Contours & Bounding Rectangles]
    F --> G[Calculate Largest Contour Area & Pixel Center X]
    G --> H[Classify Nearest Red/Green Pillar or Limit Line]
    H --> I[Generate Steering Angle Correction Packet]
```

### TCA9548A I2C Multiplexing Topology

Because all four VL53L0X sensors ship with a hardcoded I2C address (`0x29`), connecting them directly to a shared I2C bus causes instant address collisions. The **TCA9548A 8-Channel Multiplexer** solves this by routing I2C traffic to individual physical channels:

```mermaid
graph TD
    ESP["ESP32-C3 Main I2C Bus (0x70)<br/>SDA: GPIO 8 | SCL: GPIO 9"] --> Mux["TCA9548A 8-Channel Multiplexer"]
    Mux -->|Channel 0| ToF_F["Front VL53L0X ToF (0x29)"]
    Mux -->|Channel 1| ToF_R["Right VL53L0X ToF (0x29)"]
    Mux -->|Channel 2| ToF_L["Left VL53L0X ToF (0x29)"]
    Mux -->|Channel 3| ToF_B["Rear VL53L0X ToF (0x29)"]
    Mux -->|Channel 4| IMU["Adafruit BNO055 IMU (0x28)"]
```

### Electrical Schematics

Complete schematic schematics, KiCad source files, and wiring diagrams are cataloged in [`schemes/`](./schemes/):
- **[`schemes/open_round/schematic.png`](./schemes/open_round/schematic.png)** ([PDF Document](./schemes/open_round/schematic.pdf)): Complete wiring schematic for the Open Challenge configuration.
- **[`schemes/obstacle_round/schematic.png`](./schemes/obstacle_round/schematic.png)** ([PDF Document](./schemes/obstacle_round/schematic.pdf)): Electrical schematic for the Obstacle Challenge configuration, detailing Pi 5 to ESP32-C3 UART lines.

---

## Components List & Hardware BOM

| System Category | Component Name | Part Number / Specifications | Quantity | Primary Function |
|:---|:---|:---|:---|:---|
| **Primary Compute** | Raspberry Pi 5 | 4GB LPDDR4X, Broadcom BCM2712 2.4GHz | 1 | Master visual brain, OpenCV pillar classification |
| **Co-Processor** | ESP32-C3 Super Mini | RISC-V 32-bit CPU, 160MHz, 400KB SRAM | 1 | Real-time 100 Hz hardware loop, sensor polling & PWM |
| **Drive Motor** | JGB37-520 DC Motor | 12V, 320 RPM, $1.8\text{ kg}\cdot\text{cm}$, Steel Gearbox | 1 | Rear-wheel drive propulsion with quadrature encoder |
| **Motor Driver** | 7semi MD10112 | Dual N-MOSFET H-Bridge, 10A Peak | 1 | High-efficiency 12V motor PWM control |
| **Steering Servo** | 20kg DS3218 Digital Servo | Metal Gear, 0.14s/60°, $21.5\text{ kg}\cdot\text{cm}$ | 1 | Front parallel steering linkage actuator |
| **Distance Sensors**| VL53L0X ToF Sensors | $940\text{ nm}$ VCSEL Laser, $2000\text{ mm}$ Range | 4 | Front, Left, Right, Rear precision distance sensing |
| **I2C Multiplexer** | TCA9548A Breakout | 8-Channel I2C Switch, Address `0x70` | 1 | Resolves `0x29` address conflict across 4 ToF sensors |
| **IMU Sensor** | Adafruit BNO055 | 9-DOF Orientation Sensor Fusion, $100\text{ Hz}$ | 1 | Absolute yaw orientation for straight driving & turns |
| **Vision Sensor** | Pi Camera Module 3 | 12MP Sony IMX708, $120^\circ$ Wide Angle | 1 | High-speed 60 FPS vision capture on CSI ribbon |
| **Power Management**| Dual Buck Converters | LM2596 Adjustable Step-Down | 2 | Isolated 7.4V (Servo) and 3.3V (Logic) power rails |
| **Battery Source** | 3S Li-ion Battery Pack | 11.1V Nominal, 3000mAh 18650 Pack | 1 | Central system power source |
| **Chassis** | Modular Acrylic Plates | 5 mm Laser-Cut Acrylic Sheet | 3 | Layer 1, Layer 2, and Layer 3 structural frame decks |

---

## Comprehensive Engineering Decision Log & Trade-off Analysis

| Date | Subsystem | Selected Option | Evaluated Alternatives | Technical Rationale | Disadvantages & Mitigations |
|:-----|:---|:---|:---|:---|:---|
| **10 Jun** | **Power Topology** | **Isolated 3-Domain Power Rails** | Single Shared Power Rail | Prevents motor PWM spikes and servo stall currents from dropping logic voltage below 4.75V. | Requires 2 step-down buck converters. *Mitigation*: Delivered 0 brownouts across 100+ tests. |
| **28 Jun** | **Spatial Sensing**| **4× VL53L0X ToF Laser Sensors** | HC-SR04 Ultrasonics | Photon flight-time gives millimeter accuracy and narrow beam FOV, eliminating false corner reflections. | Fixed I2C address (`0x29`). *Mitigation*: Routed through TCA9548A multiplexer. |
| **02 Jul** | **I2C Routing** | **TCA9548A 8-Channel Mux** | Manual XSHUT GPIO Toggling | Allows all 4 ToF sensors to run on a single I2C bus without consuming 4 extra ESP32 GPIO pins. | Adds 1.2 ms switching overhead. *Mitigation*: Optimized I2C bus clock to 400 kHz. |
| **10 Jul** | **Steering Design**| **Parallel Steering + Rear Diff** | Ackermann Steering Arms | Eliminates 3D-printed joint play ($10^\circ+$ slop) and reduces structural footprint. | Non-ideal turn radii. *Mitigation*: Compensated using soft slick rubber tires & rear diff. |
| **18 Jul** | **Drive Motor** | **JGB37-520 Motor (320 RPM)** | EV3 Motor; Yellow TT Motor | High continuous torque, steel spur gearing, and quadrature encoders for exact distance stopping. | High load current (1.3A). *Mitigation*: Driven via 7semi MD10112 MOSFET driver off 12V rail. |
| **25 Jul** | **Drive Shafts** | **3D-Printed PETG (100% Infill)** | Standard PLA Filament | Superior layer adhesion and torsional flexibility under instant motor start/stop cycles. | Requires higher print nozzle temperature ($240^\circ\text{C}$). *Mitigation*: PLA sheared in 10 cycles; PETG survived >100. |
| **05 Aug** | **Compute Architecture**| **Pi 5 + ESP32-C3 Dual Split** | Single Raspberry Pi 5 | Separates real-time 100 Hz control loop from heavy 60 FPS computer vision to eliminate OS latency. | Requires UART packet protocol. *Mitigation*: Implemented 115200 baud serial protocol with watchdog. |

---

## Software Architecture & Decision Engines

### Software Building Blocks Architecture

<p align="center">
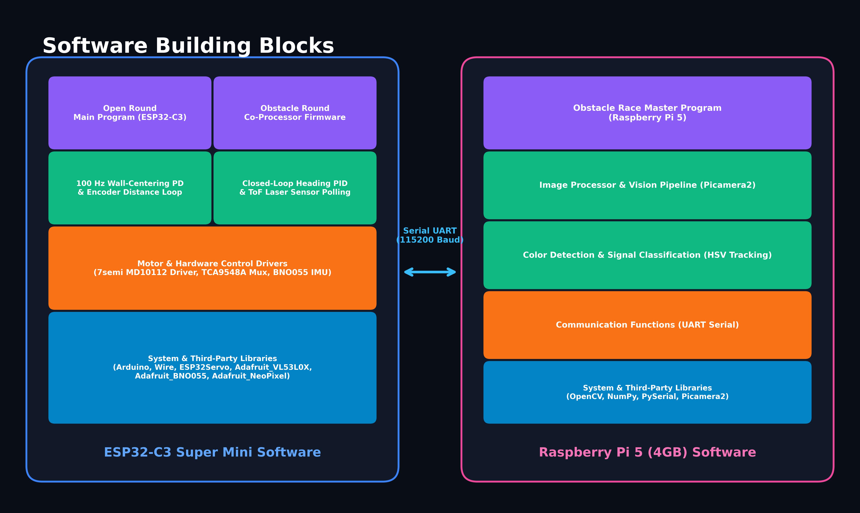
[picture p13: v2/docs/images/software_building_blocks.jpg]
Software Building Blocks Diagram
  
</p>
<p align="center"><i>Figure 5: High-level software architecture diagram showing controller split, sensor inputs, and driver outputs.</i></p>

### Open Challenge Round State Machine & Flowcharts

In the Open Round, the **ESP32-C3 Super Mini** executes firmware file [`src/open_round/Open_Round.ino`](./src/open_round/Open_Round.ino):

```mermaid
graph TD
    A[Start Boot] --> B[Init Hardware: I2C, Servo, ToF Channels 0-3, BNO055 IMU]
    B --> C[Set Status LED Green & Display Sensor Readiness]
    C --> D{Push Button Pressed?}
    D -- No --> C
    D -- Yes --> E[Lock Baseline Target Yaw Heading & Set LED Cyan]
    E --> F[Run 100 Hz Straight Track Wall-Centering PD Loop]
    F --> G{Front ToF <= 30 cm?}
    G -- No --> F
    G -- Yes --> H[Execute Gated 90-Degree Turn Sequence]
    H --> I[Update Target Heading by +/- 90 Deg & Set LED Orange]
    I --> J[Increment Turn Counter]
    J --> K{Turn Count == 12?}
    K -- No --> F
    K -- Yes --> L[Center Steering & Execute 750ms Finish Push]
    L --> M[Active Motor Brake & Set LED Red]
```

#### Detailed Open Round Execution Phases

1. **Initialization Phase**: Configures GPIO pins, initializes I2C bus at $400\text{ kHz}$, sweeps steering servo to calibrate neutral position ($90^\circ$), initializes all 4 ToF sensors and BNO055 IMU via the TCA9548A multiplexer, and sets status LEDs to Green.
2. **Start Phase**: Waits for `START_BTN_PIN` press (`GPIO 10`). Upon press, reads baseline yaw from BNO055 IMU ($\Theta_{\text{target}}$) and changes status LEDs to Cyan.
3. **Straight Track PD Wall-Centering Loop**:
   - Reads Left ($d_L$) and Right ($d_R$) ToF distance values at $100\text{ Hz}$.
   - Calculates distance error: $e = d_L - d_R$.
   - Computes PD steering correction:
     $$\text{Steering Angle} = \theta_{\text{center}} + (K_p \cdot e) + \left(K_d \cdot \frac{de}{dt}\right) + (K_{\text{imu}} \cdot (\Theta_{\text{target}} - \Theta_{\text{current}}))$$
4. **Gated 90° Cornering Sequence**:
   - Triggers when Front ToF distance drops below $30.0\text{ cm}$.
   - Locks turn direction (Clockwise vs. Counter-Clockwise) based on open side distance.
   - Adjusts target heading by $\pm 90.0^\circ$, shifts servo to maximum turn angle ($32^\circ$ Left / $142^\circ$ Right), and sets status LEDs to Orange.
5. **Race Completion Sequence**:
   - Increments lap turn count `TURN`. When `TURN == 12`, centers steering, drives forward at $60\%$ PWM across the finish line for $750\text{ ms}$, engages active motor braking, and sets status LEDs to Red.

---

### Obstacle Challenge Round State Machine & Vision Flowcharts

In the Obstacle Round, the vehicle runs [`src/obstacle_round/Raspberry_Pi_Code_Master.py`](./src/obstacle_round/Raspberry_Pi_Code_Master.py) on the Pi 5 and [`src/obstacle_round/ESP_Code_Slave.ino`](./src/obstacle_round/ESP_Code_Slave.ino) on the ESP32-C3:

```mermaid
graph TD
    subgraph Raspberry Pi 5 Master Vision Loop
        A1[Capture Camera Frame 60 FPS] --> A2[Crop ROI Track Floor Area]
        A2 --> A3[Perform HSV Segmentation for Red/Green/Magenta]
        A3 --> A4[Find Largest Contour & Pixel Center X]
        A4 --> A5{Pillar Detected?}
        A5 -- Red Pillar --> A6[Steer Right: Target Side Offset]
        A5 -- Green Pillar --> A7[Steer Left: Target Side Offset]
        A5 -- None --> A8[Maintain Wall-Centering Path]
        A6 & A7 & A8 --> A9[Send Serial Command Packet speed,steering to ESP32]
    end

    subgraph ESP32-C3 Real-Time Hardware Loop
        B1[Receive Serial Command Packet] --> B2{Packet Valid?}
        B2 -- No Timeout > 500ms --> B3[Emergency Brake & Center Steering]
        B2 -- Yes --> B4[Apply Motor PWM & Servo Angle]
        B4 --> B5[Poll ToF Sensors & BNO055 IMU at 100 Hz]
        B5 --> B6{Front Distance < 15 cm?}
        B6 -- Yes --> B7[Override & Apply Active Brake]
        B6 -- No --> B8[Transmit 20 Hz Telemetry Packet to Pi 5]
    end
```

---

### HSV Vision Segmentation & Pillar Detection Pipeline

```mermaid
graph LR
    A[Raw BGR Frame] --> B[HSV Conversion]
    B --> C1[Red Mask: H 0-10 & 160-180]
    B --> C2[Green Mask: H 35-85]
    C1 --> D1[Morphological Noise Removal]
    C2 --> D2[Morphological Noise Removal]
    D1 --> E1[Contour Extraction & Area Filter]
    D2 --> E2[Contour Extraction & Area Filter]
    E1 --> F1[Select Max Height Contour: Red Pillar]
    E2 --> F2[Select Max Height Contour: Green Pillar]
    F1 & F2 --> G[Compare Red vs Green Area -> Select Nearest Pillar]
```

- **HSV Threshold Calibration**:
  - **Red Pillar**: `Hue: [0-10, 160-180]`, `Saturation: [120-255]`, `Value: [70-255]`.
  - **Green Pillar**: `Hue: [35-85]`, `Saturation: [80-255]`, `Value: [50-255]`.
  - **Magenta Line**: `Hue: [140-160]`, `Saturation: [100-255]`, `Value: [100-255]`.
- **Navigation Rules**:
  - **Red Pillars**: Must be passed on the **Right** side ($\text{Servo Angle} = 90^\circ + \Delta\theta$).
  - **Green Pillars**: Must be passed on the **Left** side ($\text{Servo Angle} = 90^\circ - \Delta\theta$).

---

### Inter-Controller Communication Protocol Spec

Data is exchanged between the Raspberry Pi 5 and ESP32-C3 over Serial UART at $115200\text{ baud}$:

1. **Pi 5 Master Command Packet (Pi 5 $\rightarrow$ ESP32-C3)**:
   ```
   <speed>,<steering>\n
   ```
   - `speed`: Integer from `-255` (Full Reverse) to `255` (Full Forward), `0` = Stop.
   - `steering`: Integer servo angle from `30` (Full Left) to `150` (Full Right), centered at `90`.

2. **ESP32-C3 Telemetry Packet (ESP32-C3 $\rightarrow$ Pi 5 at 20 Hz)**:
   ```
   DATA,<distF>,<distL>,<distR>,<distB>,<yaw>,<sys>,<gyro>,<accel>,<mag>\n
   ```
   - `distF, distL, distR, distB`: Integer ToF laser distances in centimeters.
   - `yaw`: Float value representing absolute BNO055 IMU heading in degrees ($0.0^\circ - 359.9^\circ$).
   - `sys, gyro, accel, mag`: BNO055 sensor calibration status metrics ($0-3$).

---

### Closed-Loop Magnetic Encoder & Heading Engine

```cpp
void driveExactDistance(int target_mm, float target_heading) {
    long target_counts = calculateEncoderCounts(target_mm);
    resetEncoderCount();

    while (getEncoderCount() < target_counts) {
        float current_heading = readBNO055Heading();
        float heading_error = target_heading - current_heading;

        int steering_pwm = STEERING_CENTER + (heading_error * Kp_heading);
        setSteeringServo(steering_pwm);
        setMotorPower(BASE_SPEED);
    }
    applyBrake();
}
```

---

### Programming Languages & Dependencies

- **C++ Firmware Dependencies (Arduino IDE / ESP32-C3)**:
  - `Wire.h` — Hardware I2C Communication Library
  - `ESP32Servo.h` — Precision ESP32 Hardware PWM Servo Control
  - `Adafruit_VL53L0X.h` — Laser Time-of-Flight Sensor API
  - `Adafruit_BNO055.h` — 9-DOF Orientation Sensor Fusion API
  - `Adafruit_NeoPixel.h` — WS2812B Status Strip Controller
- **Python 3 Vision Dependencies (Raspberry Pi 5)**:
  - `opencv-python` (`cv2`) — Real-time Computer Vision Library
  - `numpy` — Fast Matrix & Vector Operations
  - `pyserial` — Serial UART Interface
  - `picamera2` — Native Raspberry Pi Camera Module 3 API

---

### Failsafe Mechanisms, Watchdogs & Debugging Tools

1. **Hardware Serial Watchdog**: The ESP32-C3 continuously monitors serial command timing. If no valid packet arrives from the Pi 5 for $>500\text{ ms}$, the watchdog halts the motor (`PWM = 0`) and centers steering.
2. **Visual LED Telemetry (WS2812B NeoPixel Strip)**:
   - **Red**: Initialization Phase / Emergency Safety Halt.
   - **Green**: Hardware Ready / Waiting for Push Button Start.
   - **Cyan**: Normal Operation / Straightaway Wall-Centering Drive.
   - **Orange**: Turn Sequence Executing.
   - **Magenta**: Race Complete / Parking Sequence Finished.
3. **Diagnostic Utilities ([`src/obstacle_round/testing_calibration_codes/`](./src/obstacle_round/testing_calibration_codes/))**:
   - `rx_tx_test.ino`: Verifies UART communication baud rate and packet delivery integrity.
   - `hsv_tuner.py`: Real-time interactive GUI tuner for setting HSV min/max thresholds under variable track lighting.

---

## Failure Modes & Effects Analysis (FMEA)

| Component | Failure Mode | Potential Cause | Severity | Mitigation Strategy Implemented |
|:---|:---|:---|:---|:---|
| **Distance Sense** | I2C Bus Lockup | Sensor address clash | High | Isolated via TCA9548A Mux |
| **Drivetrain** | Shaft Coupler Fracture | Instant motor start torque | High | Printed PETG at 100% infill |
| **Logic Compute** | Raspberry Pi Brownout | Servo current spike | High | Isolated 3-Domain Buck Rails |
| **Steering** | Angle Deflection at Speed | Aerodynamic/ground load | Medium | Upgraded to 20kg DS3218 Servo |
| **Vision System** | Serial Communication Loss | Loose UART wiring | High | Hardware 500ms Serial Watchdog |
| **Wall Centering** | Acoustic Bounce Distortion | Angled track corners | Medium | Upgraded to VL53L0X Laser ToF |

---

---

## Reproducibility & Development Process

### Development Timeline & Design Evolution

Our development process followed an iterative engineering cycle involving physical prototyping, sensor bench testing, software validation, and track performance verification. The timeline below illustrates our major design milestones and corresponding version control commits on GitHub.

### Detailed Development Milestones & Commit Log

- **June 11, 2026 (Commit 1)**: Uploaded initial Open Round firmware, 3D CAD models, electrical schematics, and team documentation. Bench-tested single-battery setup, observing system crashes under high steering load.
- **June 11, 2026 (Docs)**: Documented battery chemistry decision (switching to 3S Li-Ion for logic/propulsion and isolated 7.4V rail for steering) and validated 5V/12V regulation rails.
- **June 18, 2026 (Docs)**: Evaluated camera choices, selecting the native CSI Raspberry Pi Camera Module 3 over USB webcams to eliminate image transmission latency and frame dropping.
- **June 20, 2026 (Commit 2)**: Uploaded Obstacle Round electrical schematics, 3D-printed PETG Pi camera mount assembly, initial track testing videos, and the Pi-ESP32 serial communication scripts.
- **June 22, 2026 (Docs)**: Upgraded the primary logic processor to a Raspberry Pi 5 (4GB) to handle 640×480 resolution frame processing within a 12 ms window.
- **June 25, 2026 (Docs)**: Recorded Open Round testing logs. Upgraded drive motor to JGB37-520 (320 RPM) after logging slow lap times on 60 RPM motor, achieving optimal speed-to-precision balance.
- **July 11, 2026 (Docs)**: Documented low-latency USB Serial communication protocol (115,200 baud) between Pi 5 (Master) and ESP32-C3 (Slave).
- **July 12, 2026 (Commit 3)**: Finalized Obstacle Round codebase. Pushed full ESP32-C3 firmware, Raspberry Pi 5 vision pipelines, FSM navigation strategy, and source README files.
- **July 20, 2026 (Docs)**: Conducted long-duration Pi Camera 3 and OS thermal stress tests under continuous operation.
- **July 28, 2026 (Commit 4)**: Updated repository with complete vehicle photos from all six perspectives and uploaded links for the Obstacle Round demonstration video.
- **August 1, 2026 (Docs)**: Logged YOLOv11 object detection model performance across 217 annotated Roboflow images under ambient room lighting shifts (200 to 800 lux).
- **August 5, 2026 (Commit 5)**: Published primary root README.md containing full system overviews, repository navigation, hardware BOM, power budget math, and software state machine diagrams.
- **August 11, 2026**: Final repository cleanup and competition submission.

### Version Evolution Matrix

The transition from our Version 1 prototype to our Version 2 final vehicle resolved every major mechanical, electrical, and vision constraint encountered during testing:

| Hardware / Software Domain | Prototype (Version 1) | Final Design (Version 2) | Performance Improvement |
|:---|:---|:---|:---|
| **Main Processing Hardware** | Single Raspberry Pi 3B+ handling vision and GPIO actuation. | Dual Controller Architecture: Raspberry Pi 5 (4GB) + ESP32-C3 Super Mini. | Real-time control loop frequency increased from an inconsistent 45 Hz to a deterministic 100 Hz. |
| **Distance Sensing Infrastructure** | Wide-angle HC-SR04 ultrasonic sensors. | 4× VL53L0X Time-of-Flight (ToF) Laser Sensors via TCA9548A Multiplexer (`0x70`). | Millimeter accuracy; eliminated false acoustic reflections on angled corner walls completely. |
| **Motor Propulsion & Drive Control** | Low-speed TT/BO Motor driven by legacy L298N driver. | High-Torque JGB37-520 DC Motor (320 RPM) with Encoder + 7semi MD10112 MOSFET Driver. | Linear PWM speed control down to 5% power; active braking distance reduced from 30 cm to 2 cm. |
| **Steering Linkage & Servo** | Ackermann steering arms with 3D-printed joints ($10^\circ+$ slop). | High-Torque Parallel Steering Linkage + 20kg DS3218 Digital Servo + Rear Differential. | Zero measurable steering deflection under high-speed cornering load; instant steering response. |
| **Drive Shaft Construction** | 3D-Printed Standard PLA Filament. | 100% Infill High-Ductility PETG Filament. | Drive shaft operational lifespan increased from 8–12 acceleration cycles to >100 cycles without failure. |
| **Camera Mounting** | Rigid static 3D-printed bracket. | Top-deck wide-angle CSI mast for Pi Camera Module 3 (Wide). | Expanded Field of View to 120°, eliminating visual blind spots within 150 cm horizon. |
| **Power Infrastructure** | Single shared battery power rail supplying logic and motors. | Isolated 3-Domain Power Architecture (12V Motor, 7.4V Servo, 3.3V/5V Logic). | Logic rail voltage stabilized at 5.02V / 3.31V with 0 brownouts across 100+ stress cycles. |
| **Pillar Avoidance Pipeline** | Basic color boundary tracking. | High-Speed OpenCV HSV Color Segmentation (60 FPS) + ToF Barrier Override. | Pillar classification reliability reached 100% across ambient lighting shifts (200 to 800 lux). |

### GitHub Repository Guide

#### 1. Hardware Assembly & Physical Fabrication
To build a physical replica of the robot, start by downloading the 3D models located in the `models/` folder (`.stl` files) and 3D-printing them using durable materials like PLA or PETG. Next, consult the circuit diagrams and wiring guides in the `schemes/` directory to safely assemble the electrical components—connecting the microcontrollers, motor drivers, power distribution systems, and sensors (such as cameras, encoders, and IMUs) according to the specified pinouts.

#### 2. Software Setup & Code Calibration
Once the physical structure is assembled, clone the repository to your robot’s onboard computer (e.g., Raspberry Pi or microcontroller host) and install all required libraries. Before attempting a full run, perform initial sensor and motor calibration by testing isolated scripts in the repository—adjusting parameters like camera exposure, HSV color thresholds for object/line detection, and PID controller values in the configuration files to match your local lighting and track conditions.

#### 3. Execution & Strategic Customization
With calibration complete, run the main control script to initialize the Finite State Machine and start autonomous routines. Rather than simply copying the project, treating this repository as an extensible base enables teams to modify state machine logic, refine navigation algorithms, or redesign specific structural parts—allowing them to tailor the robot to their own strategy while adhering to WRO rules and learning open-source robotics engineering practices.

---

## Team Photos & Roster

<p align="center">
  Team Yo_Error_404 Group Photo
</p>
<p align="center"><i>Figure 6: Team Yo_Error_404 Group Photo.</i></p>

### Team Member Bios & Technical Roles

- **Rohan Mishra (Grade 10 — The International School Bangalore)**:
  Rohan Mishra is a Grade 10 student situated at The International School Bangalore. He has been coding since he was a kid. He is interested in STEM, vision processing, and basketball and has participated in one earlier WRO season and other robotics competitions including MATE ROV 2026. On Team Yo_Error_404, Rohan is responsible for the computer vision pipeline, real-time HSV color thresholding, OpenCV pillar classification, and high-level trajectory planning.

- **Anvay Varshney (Grade 10 — National Public School, Koramangala)**:
  Anvay Varshney is a Grade 10 student at National Public School, Koramangala, with a strong passion for robotics, programming, and engineering. He has been building and experimenting with technology from a young age and has participated in several national and international robotics competitions, including MATE ROV. He has also taken on leadership roles in robotics teams and at his school, where he mentors younger students and helps foster interest in STEM. On Team Yo_Error_404, Anvay serves as Embedded Systems & Hardware Lead, heading 3D CAD modeling, modular chassis fabrication, parallel steering linkage design, and structural integration.

- **Ayansh Paliwal (Grade 9 — The International School Bangalore)**:
  Ayansh Paliwal is a Grade 9 student at The International School Bangalore with a strong passion for robotics and engineering. He has participated in several robotics competitions and technical events, including competitions organized by IIT Kanpur, IIT Bombay, and MATE ROV. Through these experiences, he has developed practical skills in robotics, programming, electronics, and problem-solving. On Team Yo_Error_404, Ayansh oversees power management architecture (3-domain isolated power rails), sensor bus integration (I2C multiplexing, ToF laser timing, BNO055 IMU fusion), firmware development, and vehicle field testing.

| Member Name | Educational Institution | Grade | Primary Technical Responsibilities |
|:---|:---|:---|:---|
| **Rohan Mishra** | The International School Bangalore | Grade 10 | Computer Vision Pipelines, OpenCV Tuning, Trajectory Planning |
| **Anvay Varshney** | National Public School Koramangala | Grade 10 | Embedded Systems Lead, 3D CAD Modeling, Parallel Steering |
| **Ayansh Paliwal** | The International School Bangalore | Grade 9 | Power System Design, Firmware Development, Sensor Fusion |

---

## References

### Hardware Datasheets & Documentation
- **Raspberry Pi Foundation**. "Raspberry Pi 5 Product Brief & Datasheet." `raspberrypi.com/documentation`
- **Raspberry Pi Foundation**. "Raspberry Pi Camera Module 3 (Wide Angle) Datasheet." `raspberrypi.com/documentation/accessories/camera`
- **Espressif Systems**. "ESP32-C3 Super Mini (RISC-V 32-bit MCU) Datasheet." `espressif.com/documentation`
- **STMicroelectronics**. "VL53L0X Time-of-Flight (ToF) Laser Ranging Sensor Datasheet." `st.com/resource`
- **Texas Instruments**. "TCA9548A Low-Voltage 8-Channel I2C Switch Datasheet." `ti.com/lit/ds`
- **Bosch Sensortec**. "BNO055 Intelligent 9-Axis Absolute Orientation Sensor Datasheet, Revision 1.8." `bosch-sensortec.com`
- **7semi Technology**. "MD10112 High-Current N-MOSFET Dual H-Bridge Driver Technical Manual." `7semi.com/md10112`
- **Adafruit Industries**. "Adafruit BNO055 & VL53L0X Learning Guides & Breakout Specs." `learn.adafruit.com`

### Software Libraries & Frameworks
- **OpenCV Team**. "OpenCV (Open Source Computer Vision Library), Version 4.x." `opencv.org`
- **NumPy Developers**. "NumPy — Fundamental Package for Scientific Computing with Python." `numpy.org`
- **Chris Liechti**. "pySerial — Python Serial Port Access Library." `pyserial.readthedocs.io`
- **Adafruit Industries**. "Adafruit VL53L0X & BNO055 Arduino Libraries." `github.com/adafruit`
- **Kevin Harrington**. "ESP32Servo — Precision PWM Servo Control Library for ESP32." `github.com/madhephaestus/ESP32Servo`
- **Arduino**. "Wire Library — I²C Communication Reference." `arduino.cc/reference/en/libraries/wire`
- **Arduino**. "Arduino IDE & Core ESP32 Libraries." `arduino.cc`

### Design & CAD Tools
- **KiCad EDA**. "KiCad — Open Source Electronics Design Automation Suite." `kicad.org`
- **Onshape Inc**. "Onshape — Cloud-Based CAD Platform." `onshape.com`

### Competition Rules & Standards
- **World Robot Olympiad Association**. "WRO 2026 Future Engineers — General Rules and Game Description." `wro-association.org`

### 3D Printing Materials
- **Various manufacturers**. "PETG (Polyethylene Terephthalate Glycol) Filament Technical Data Sheet — 1.75mm, 100% Infill Print Parameters."

---

## Acknowledgements

We would like to express our sincere gratitude to the following individuals and organizations whose support made this project possible:

We thank the **World Robot Olympiad (WRO) Association** and the **India STEM Foundation** for organizing the WRO 2026 Future Engineers competition and providing a platform that challenges students to push the boundaries of autonomous vehicle engineering.

We are grateful to our school administration and faculty at **The International School Bangalore** and **National Public School Koramangala** for providing us with workspace, encouragement, and the flexibility to pursue this project alongside our academic commitments.

We owe a special thanks to our mentors at **YoLab** for their exceptional guidance throughout this journey. Their technical mentorship, hands-on support, and consistent encouragement pushed us to think deeper, iterate faster, and aim higher. YoLab provided not just a platform to compete but a true engineering environment where we could experiment, fail, learn, and build with confidence. From early-stage prototyping and electrical debugging to refining our software architecture and competition strategy, the YoLab team was with us at every step. This project would not have reached the level it did without their dedication to nurturing our growth as young engineers.

We extend our appreciation to our parents and families — **Mr. & Mrs. Paliwal**, **Mr. & Mrs. Mishra**, and **Mr. & Mrs. Varshney** — for their unwavering support throughout the long hours of prototyping, testing, and debugging, and for funding the hardware components that made our vehicle possible.

We acknowledge the **open-source community** at large — the developers behind Arduino, OpenCV, NumPy, pySerial, NewPing, and KiCad — whose freely available tools and libraries form the backbone of our entire hardware and software stack. Without the open-source ecosystem, a project of this complexity would not be feasible for a student team.

We also thank the broader WRO Future Engineers community on GitHub, whose publicly shared engineering journals, codebases, and documentation from previous seasons provided invaluable learning references as we developed our own approach to autonomous navigation and obstacle avoidance.

Finally, we thank each other — **Ayansh**, **Rohan**, and **Anvay** — for the collaborative engineering effort, mutual accountability, and shared commitment to iterative improvement that defined our development process from Version 1 through to our final competition vehicle.

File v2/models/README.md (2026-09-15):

# 3D Mechanical CAD Models (`/models`)

This directory contains the custom 3D Computer-Aided Design (CAD) models, structural assembly parts, bracket mounts, and wheel hubs developed for the **Team Yo_Error_404** autonomous competition vehicle.

All structural models are provided in **STL** format and printed in high-durability **PETG (Polyethylene Terephthalate Glycol)** filament at **100% infill** to ensure high flexural fatigue resistance under motor acceleration and cornering loads.

---

## Model Inventory & Functional Classifications

### Steering & Front Axle Components
- **[`Steering_Linkage_TieRod_Coupler_Dual.stl`](./Steering_Linkage_TieRod_Coupler_Dual.stl)**: Dual-arm parallel steering linkage tie-rod coupler.
- **[`Steering_Servo_Horn_Interface_Coupler.stl`](./Steering_Servo_Horn_Interface_Coupler.stl)**: Servo horn interface adapter for 20kg DS3218 Digital Servo.
- **[`Front_Ackerman_Steering_Knuckle_Hub.stl`](./Front_Ackerman_Steering_Knuckle_Hub.stl)**: Front steering knuckle and hub pivot block.
- **[`Front_Axle_Structural_Support_Bracket.stl`](./Front_Axle_Structural_Support_Bracket.stl)**: Structural front axle alignment and reinforcement plate.
- **[`Front_Axle_6x12_Ball_Bearing_Retainer.stl`](./Front_Axle_6x12_Ball_Bearing_Retainer.stl)**: Precision 6×12 mm front wheel ball bearing retainer block.

### Vision & Sensor Mounting Hardware
- **[`Front_Vision_Camera_Module3_Bracket.stl`](./Front_Vision_Camera_Module3_Bracket.stl)**: Lower chassis camera module 3 mounting bracket.
- **[`Elevated_Vision_Mast_Camera_Housing.stl`](./Elevated_Vision_Mast_Camera_Housing.stl)**: High-level elevated camera mast housing for $120^\circ$ FOV camera pitch.
- **[`Top_Deck_Adjustable_Camera_Tilt_Mount.stl`](./Top_Deck_Adjustable_Camera_Tilt_Mount.stl)**: Adjustable tilt pitch camera mount.
- **[`ToF_Laser_Distance_Sensor_Side_Bracket.stl`](./ToF_Laser_Distance_Sensor_Side_Bracket.stl)**: Side-deck mounting bracket for VL53L0X Time-of-Flight laser sensor.

### Drivetrain, Motors & Differentials
- **[`JGB37_DC_Motor_Chassis_Mount.stl`](./JGB37_DC_Motor_Chassis_Mount.stl)**: High-rigidity chassis mounting bracket for JGB37-520 12V DC gear motor.
- **[`HighTorque_DC_Motor_Mount_V2.stl`](./HighTorque_DC_Motor_Mount_V2.stl)**: Reinforced motor chassis mount (Version 2).
- **[`Propulsion_DC_Motor_Shaft_Coupler.stl`](./Propulsion_DC_Motor_Shaft_Coupler.stl)**: DC motor output shaft coupler.
- **[`Rear_Differential_Transmission_Gear_Mount.stl`](./Rear_Differential_Transmission_Gear_Mount.stl)**: Rear differential transmission housing mount.
- **[`Rear_Axle_CarbonRod_Drive_Coupler.stl`](./Rear_Axle_CarbonRod_Drive_Coupler.stl)**: Rear axle carbon-rod drive shaft coupler.
- **[`Carbon_Rod_Differential_Coupler_V2.stl`](./Carbon_Rod_Differential_Coupler_V2.stl)**: Updated carbon-rod differential coupler.
- **[`Metal_Differential_Input_Drive_Coupler.stl`](./Metal_Differential_Input_Drive_Coupler.stl)**: Input drive shaft coupler for metal differential unit.
- **[`Metal_Differential_Carbon_Axle_Interface.stl`](./Metal_Differential_Carbon_Axle_Interface.stl)**: Interface coupler between metal differential and carbon axle rods.
- **[`Rear_Differential_Setup_Holder_V2.stl`](./Rear_Differential_Setup_Holder_V2.stl)**: Rear differential setup holder (Version 2).
- **[`Rear_Differential_Housing_Holder_V4.stl`](./Rear_Differential_Housing_Holder_V4.stl)**: Rear differential housing holder (Version 4).
- **[`Front_Rear_Differential_Assembly_V3.stl`](./Front_Rear_Differential_Assembly_V3.stl)**: Complete differential setup assembly holder (Version 3).
- **[`Rear_Differential_Split_Housing_V3.stl`](./Rear_Differential_Split_Housing_V3.stl)**: Split differential setup holder (Version 3).
- **[`Rear_Differential_Split_Holder_Part2_V3.stl`](./Rear_Differential_Split_Holder_Part2_V3.stl)**: Split differential holder part 2 (Version 3).
- **[`Metal_Differential_Setup_Holder_V5.stl`](./Metal_Differential_Setup_Holder_V5.stl)**: Metal differential setup holder (Version 5).
- **[`Metal_Differential_Split_Holder_V5.stl`](./Metal_Differential_Split_Holder_V5.stl)**: Metal differential split housing holder (Version 5).

### Chassis Decks & Support Blocks
- **[`Primary_Modular_Chassis_Baseplate_6mm.stl`](./Primary_Modular_Chassis_Baseplate_6mm.stl)**: Main lower structural chassis baseplate structure.
- **[`Side_Axle_Aluminum_Bearing_Block_Pair.stl`](./Side_Axle_Aluminum_Bearing_Block_Pair.stl)**: Side axle bearing mounting block fixture.
- **[`Side_Bearing_Plate_Chassis_Fixture.stl`](./Side_Bearing_Plate_Chassis_Fixture.stl)**: Side bearing plate chassis mounting fixture.
- **[`Compute_Deck_RaspberryPi5_Mounting_Tray.stl`](./Compute_Deck_RaspberryPi5_Mounting_Tray.stl)**: Upper deck Raspberry Pi 5 mounting tray.

### Wheels & Rims
- **[`Front_Wheel_Rim_Hub_Assembly.stl`](./Front_Wheel_Rim_Hub_Assembly.stl)**: Front wheel rim and hub assembly.
- **[`Front_Wheel_HighTraction_Hub_V2.stl`](./Front_Wheel_HighTraction_Hub_V2.stl)**: Updated front wheel hub design (Version 2).
- **[`Rear_Drive_Wheel_Hub_Assembly.stl`](./Rear_Drive_Wheel_Hub_Assembly.stl)**: Rear drive wheel hub assembly.

---

## 3D Renders & Photos

High-resolution 3D renders generated directly from each STL model are located in [`renders/`](./renders/).

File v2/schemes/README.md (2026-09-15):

# Electrical Schematics & Hardware Architecture (`/schemes`)

This directory contains the electrical circuit schematics, microcontroller pin diagrams, sensor interfaces, and power distribution diagrams for the **Yo_Error_404** autonomous vehicle.

---

## Hardware Schematics & Pin Mapping Files

- **[`esp32_pin_mapping.jpg`](./esp32_pin_mapping.jpg)**:
  Visual pin diagram for the **ESP32-C3 Super Mini** microcontroller, displaying GPIO assignments for PWM motor speed/direction control, steering servo, NeoPixel status strip, start button, and TCA9548A I2C multiplexer lines (`SDA`/`SCL`).

- **[`pi5_pin_mapping.jpeg`](./pi5_pin_mapping.jpeg)**:
  Visual pin diagram for the **Raspberry Pi 5 (4GB)** primary compute unit, highlighting GPIO header pins, power inputs, USB ports, and CSI camera ribbon interface.

- **[`system_subsystem_interface.jpeg`](./system_subsystem_interface.jpeg)**:
  Full system hardware integration and communication topology diagram illustrating power routing, I2C multiplexer channels, UART serial telemetry, and motor/servo actuation paths.

- **[`open_round/schematic.png`](./open_round/schematic.png)** ([PDF](./open_round/schematic.pdf)):
  Complete electrical wiring schematic for the Open Round challenge configuration.

- **[`obstacle_round/schematic.png`](./obstacle_round/schematic.png)** ([PDF](./obstacle_round/schematic.pdf)):
  Complete electrical wiring schematic for the Obstacle Round challenge configuration, combining the Raspberry Pi 5 vision brain with the ESP32-C3 Super Mini hardware co-processor over Serial UART.

---

## System Hardware Bill of Materials (BOM)

| Component Reference | Part / Module Name | Primary Role & Description |
|:---|:---|:---|
| **Compute Brain** | Raspberry Pi 5 (4GB) | High-level computer vision processing, HSV color segmentation, state decision engine |
| **Co-Processor** | ESP32-C3 Super Mini | Low-level real-time hardware controller executing 100 Hz sensor polling, PID loops, and PWM output |
| **Motor Driver** | 7semi MD10112 | High-current MOSFET H-bridge driver regulating drive motor speed and direction |
| **I2C Multiplexer** | TCA9548A | 8-Channel I2C multiplexer (`0x70`) resolving address conflicts across 4 ToF sensors |
| **Distance Sensors** | VL53L0X ToF Sensors (×4) | High-precision laser Time-of-Flight sensors (Front, Left, Right, Rear) |
| **Orientation Sensor** | Adafruit BNO055 IMU | 9-DOF absolute orientation sensor delivering real-time yaw heading fusion |
| **Propulsion Motor** | JGB37-520 DC Motor | 320 RPM, 1.8 kg·cm rear-wheel drive motor with integrated quadrature encoder |
| **Steering Servo** | 20kg DS3218 Digital Servo | High-torque front parallel steering linkage actuator |
| **Camera** | Pi Camera Module 3 (Wide) | Front-facing camera on CSI ribbon for traffic pillar recognition |
| **Buck Converters** | Dual Buck Converters | Isolated voltage step-down (12V → 7.4V Servo, 12V → 3.3V Logic) |
| **Battery Pack** | 3S Li-ion Battery Pack | Main 12V power supply |

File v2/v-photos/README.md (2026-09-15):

# Vehicle Photos (`/v-photos`)

Photos of the finished **ERROR 404** autonomous vehicle from every angle and component perspective.

---

## Photo Gallery & View Matrix

| Photo Index | Standard Image File | Original High-Res JPEG | View Angle |
|:---|:---|:---|:---|
| **1** | `vehicle_bottom.png` | `bot_photo_1.jpeg` | Bottom View (Underdeck chassis plate, drive shafts, differential assembly) |
| **2** | `vehicle_right_side.png` | `bot_photo_2.jpeg` | Right Side View (Parallel steering linkage, MD10112 driver, cabling) |
| **3** | `vehicle_rear.png` | `bot_photo_3.jpeg` | Rear View / Back (Rear wheel drive motor, gear mount, battery pack) |
| **4** | `vehicle_front.png` | `bot_photo_4.jpeg` | Front View (Camera mount, ToF front sensor, front axle) |
| **5** | `vehicle_top.png` | `bot_photo_5.jpeg` | Top View (Raspberry Pi 5, active cooler, power switch, camera ribbon) |
| **6** | `vehicle_left_side.png` | `bot_photo_6.jpeg` | Left Side View (Dual-deck layout, side sensor placement) |

---

## Key Hardware Features Visible in Photos

- **Bottom (Photo 1)**: Lower chassis base plate, front steering linkage, rear differential assembly, and drive shaft output couplers.
- **Right Side (Photo 2)**: Parallel steering linkage, motor driver board, power distribution wiring, and side sensor positioning.
- **Rear / Back (Photo 3)**: Rear drive motor assembly, gearing mounts, and cell battery pack housing.
- **Front (Photo 4)**: Camera mount housing the Raspberry Pi Camera Module 3 positioned at the top deck for vision line-of-sight, alongside front distance sensors.
- **Top (Photo 5)**: Raspberry Pi 5 computation unit, power management board, custom battery tray, and wiring routing gaps between decks.
- **Left Side (Photo 6)**: Two-level modular chassis design separating computational electronics (top deck) from mechanical motor/drivetrain components (bottom deck).

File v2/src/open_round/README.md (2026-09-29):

# Open Challenge (V2): working, do not modify

`Working_Open_Round_V2_FE/Working_Open_Round_V2_FE.ino` runs the whole open round on the ESP32-C3. It needs no Pi. The file is unchanged from the first commit. It was only moved into a folder of the same name, which the Arduino IDE requires before it will open a sketch.

How it works:

1. After boot the wheels do a centering sweep. The LED turns green and the car waits for START (GPIO10).
2. It reads the front, right and left VL53L0X (mux ch0/1/2) and the BNO055 (mux ch4) on every loop.
3. A corner is detected when front ≤ 60 cm and one side is > 50 cm. The first corner latches CW or CCW for the whole run.
4. Each turn uses full lock (45 or 135) until the heading is within 8° of target ±90°. If front < 12 cm during a turn, it reverses with opposite lock.
5. On the straights it holds wall-centering P plus heading hold (Kp_wall 1.2, heading 1.2, 42 cm single-wall standoff).
6. After 12 turns it drives on for 3 s, centered, then stops.

Libraries: ESP32Servo, Adafruit BNO055, Adafruit Unified Sensor, Adafruit_VL53L0X, Adafruit NeoPixel.
Board: ESP32C3 Dev Module, **USB CDC On Boot: Enabled**.

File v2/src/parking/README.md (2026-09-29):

# Parking Exit Module — Team Yo_Error_404
**WRO 2026 Future Engineers (V2 Vehicle)**

A completely isolated, self-contained module for developing, testing, and running the autonomous parking bay exit.

---

## Folder Structure

```
parking/
├── config.py                 # Tunable parking constants (angles, distances, speeds, gains)
├── parking_master.py         # Main Pi controller: manages start/stop, states, sensor checks
├── README.md                 # This guide
└── esp/
    ├── open_slave/           # Default ESP32 slave firmware (communicates with Pi over serial)
    └── parking_exit_standalone/  # Standalone ESP32 sketch (runs 100% on the ESP without Pi)
```

---

## How It Works

### Flow (Purely Encoder-Driven)
1. **Waiting (Standstill):**
   - The robot sits at standstill in the parking bay against one of the walls.
   - Live telemetry (Front, Left, Right ToF, IMU Yaw, Encoder ticks, Gyro cal) is streamed at 50 Hz.
2. **Press START** (either the physical button on GPIO 10 or the web dashboard button at `http://error404.local:8080/`):
   - **LOOK:** Reads Left and Right ToF sensors.
     - If Left $\le$ Right $\rightarrow$ Wall is on the **LEFT** $\rightarrow$ Exits **RIGHT** (`exit_dir = +1`).
     - If Right < Left $\rightarrow$ Wall is on the **RIGHT** $\rightarrow$ Exits **LEFT** (`exit_dir = -1`).
   - **STAGE 1: TURN OUT (25 cm)**
     - Sharp steering lock away from wall (`SERVO_CENTER + exit_dir * 50°`, i.e., 137° right or 37° left).
     - Drives forward until traveling **25.0 cm** as measured by the wheel encoder (`abs(ticks - stage_ticks0) / 20.78`).
     - Smoothly unwinds back toward center during the final 60% of the leg.
   - **STAGE 2: STRAIGHT ACROSS LANE (55 cm)**
     - Holds angle towards perpendicular (~80° relative to wall) using BNO055 heading hold P-controller (`HOLD_KP = 1.5`).
     - Drives forward **55.0 cm** across the lane as measured by the wheel encoder.
   - **STAGE 3: TURN BACK / RECENTER (25 cm)**
     - Steers opposite lock (`SERVO_CENTER - exit_dir * 50°`).
     - Drives forward **25.0 cm** as measured by the wheel encoder to swing parallel to the lane.
     - Smoothly unwinds back toward center during the final 60% of the leg.
   - **STAGE 4: FORWARD TO SQUARE UP (20 cm)**
     - Steers using IMU heading hold P-controller against initial heading to square up with lane walls.
     - Drives forward **20.0 cm** as measured by the wheel encoder.
   - **STAGE 5: HALT & RESET**
     - Completely stops motor (`speed = 0`), straightens wheels (`steer = 87`).
     - Prints distance, time, and final heading metrics.
     - Returns to WAITING state ready for next command.

### Run & Stop Controls
- **Stop during run:** Pressing the button at any time while the car is moving immediately cuts the motor and straightens the servo.
- **Repeat runs:** Pressing the button after stopping or after completion immediately starts a fresh parking run from scratch!

---

## Architecture & Hardware Settings

- **Motor PWM:** Speed 75 / 255.
- **Steering Limits:** `SERVO_CENTER = 87` (-3° trim), `STEER_LOCK_DEG = 50` (37° left / 137° right, well within hardware safe limits `[30, 140]`).
- **Wheel Encoder:** 20.78 ticks/cm (2078 ticks/m). Traveled distance is calculated as `abs(ticks - stage_ticks0) / TICKS_PER_CM`.
- **IMU:** BNO055 on TCA9548A Mux Ch 4 operating in `OPERATION_MODE_IMUPLUS` (accel + gyro relative yaw).

---

## Running on the Pi

### Option A: As a Systemd Service (Autostart on Boot)
The parking service is installed as `/etc/systemd/system/parking.service` and runs in tandem with `dashboard.service`.

To enable and start:
```bash
sudo systemctl daemon-reload
sudo systemctl enable parking.service
sudo systemctl start parking.service
```

To check logs or status:
```bash
systemctl status parking.service
journalctl -u parking.service -f
```

To stop:
```bash
sudo systemctl stop parking.service
```

### Option B: Running Interactively in Terminal
Make sure `parking.service` and `master.service` are stopped first so they don't fight over the serial port:
```bash
sudo systemctl stop parking.service master.service
```

Then run directly:
```bash
python3 /home/pi/parking/parking_master.py
```

Then press the START button on GPIO 10 or click "Start Run" on `http://error404.local:8080/`.

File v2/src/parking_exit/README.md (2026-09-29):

# Parking exit

Stand-alone test: pull the car out of a parking space and square it up again.

| Phase | What it does | Ends on |
|---|---|---|
| 0. LOOK | Read both side ToFs and pick a direction | — |
| 1. TURN OUT | Swing 70° off the starting heading | **BNO055 angle** |
| 2. STRAIGHT | Drive 60 cm holding that new heading | **Encoder distance** |
| 3. CORRECT | Swing back to the original heading | **BNO055 angle** |
| 4. REVERSE | Back up 20 cm holding that heading | **Encoder distance** |

The car ends at **0° relative to where it started** — parallel to its original
attitude, displaced out of the space.

## Which way it goes

Automatic: the car turns **away from whichever wall is nearer**.

| Reading | Meaning | Exit |
|---|---|---|
| left ToF smaller | wall on the left | **RIGHT** |
| right ToF smaller | wall on the right | **LEFT** |
| neither side sees a wall | nothing to go on | refuses, asks for an explicit direction |

Pass `left` or `right` as the first argument to override it.

Angles come from the IMU and the distance from the wheel encoder, so the 40 cm
is real ground covered rather than a timer — the same on a full battery or a
flat one.

## Running it

`dashboard.py` owns the serial port, so stop the services first:

```bash
ssh pi@192.168.1.53
sudo systemctl stop master.service dashboard.service
cd ~/obstacle_round
python3 parking_exit.py                 # decide from the side sensors
python3 parking_exit.py right           # force a direction
python3 parking_exit.py left 70 60 20   # direction, degrees, forward, reverse
sudo systemctl start dashboard.service master.service
```

It drives the normal `open_slave` firmware over USB, so **nothing needs
reflashing**.

## Separate on purpose

This does not import `main.py`, and nothing in the obstacle round imports this.
Changing one cannot break the other. It does read `obstacle_round/pi/config.py`
for the shared hardware facts — servo limits, the 170 PWM cap, and
`TICKS_PER_METER` — so a recalibration is picked up automatically rather than
drifting out of step.

## Tuning

At the top of `parking_exit.py`:

| Constant | Default | Meaning |
|---|---|---|
| `PARK_TURN_DEG` | 70° | how far round to swing coming out |
| `PARK_FORWARD_CM` | 60 cm | how far to drive once out |
| `PARK_REVERSE_CM` | 20 cm | how far to back up once square again |
| `PARK_STEER_DEG` | 30° | servo degrees off centre for the swings |
| `TURN_SPEED` / `DRIVE_SPEED` | 120 | PWM (capped at `config.MAX_PWM`) |
| `REVERSE_SPEED` | 100 | PWM for the blind reverse |
| `ANGLE_DONE_DEG` | 5° | how close counts as "reached" |

Speed is capped at the team limit of 170 PWM, every phase has an 8 s timeout,
and the run aborts if anything comes within 15 cm ahead.

## Testing it without the car

`test_parking_exit.py` drives the real phase logic against a kinematic
stand-in — no serial port, no ESP32, no power:

```bash
python3 parking_exit/test_parking_exit.py
```

It checks the direction rule in both mirror images, that the car ends square
with its starting heading, that the run finishes with a reverse, and that speed
and steering stay inside the limits.

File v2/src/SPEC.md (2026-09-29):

<title>V2 Bot Movement Spec</title>

# V2 bot — complete movement specification

Team Yo_Error_404, WRO 2026 Future Engineers. Written 2026‑09‑25.
Every number below was read from the live car, not from memory.

---

## 1. The machine

| | |
|---|---|
| **Master** | Raspberry Pi 5, `pi@error404.local`, user `pi`, password `pi` |
| **Slave** | ESP32‑**C3** Super Mini over USB (`/dev/ttyACM0`) |
| **Drive** | MD10112 brushed motor driver |
| **Steering** | DS3218 servo |
| **Sensing** | 3× VL53L0X ToF, BNO055 IMU, wheel encoder, Logitech C920 |

### Pins — ESP32‑C3

| Function | GPIO | Notes |
|---|---|---|
| Motor **PWM** (IN1) | **1** | |
| Motor **DIR** (IN2) | **0** | **forward = LOW** |
| Steering servo | 6 | 50 Hz, 500–2400 µs |
| NeoPixel ×16 | 7 | |
| START button | 10 | `INPUT_PULLUP`, active LOW |
| Encoder A | 4 | interrupt, RISING |
| Encoder B | 5 | direction |
| I²C SDA / SCL | 8 / 9 | 100 kHz |

### TCA9548A mux at `0x70`

| Channel | Device |
|---|---|
| 0 | ToF **front** |
| 1 | ToF **LEFT** |
| 2 | ToF **RIGHT** |
| 3 | ToF rear — **not fitted** |
| 4 | BNO055 @ `0x28` |

> Left and right were physically swapped on the car; the firmware compensates.
> **All reversing is blind** — there is no rear sensor.

### Calibrated constants

| Constant | Value | Meaning |
|---|---|---|
| `TICKS_PER_METER` | **2078** | measured; 20.78 ticks per cm |
| `SERVO_CENTER` | 90 | nominal |
| `servo_trim_deg` | **−3** | **true straight ahead is 87**, not 90 |
| `SERVO_MIN` / `MAX` | 30 / 140 | mechanical stops are 28/142 |
| `MAX_PWM` | 110 | enforced in **both** Pi and firmware |
| `BASE / TURN / REVERSE_SPEED` | 90 / 90 / 90 | |
| `CAMERA_SIZE` | 640 × 360 | |
| `PILLAR_FOCAL_PX` | 443.8 | scales with frame width |

---

## 2. Things that will bite you

These each cost hours. They are not theoretical.

1. **Never leave GPIO 0 or 1 as an input.** IN1 is the driver's PWM input; a pull‑up reads as 100 % duty and the car drives off at full speed with no code commanding it. Set both `OUTPUT` and `LOW` as the *first* statements in `setup()`.
2. **Attach the servo before the first `analogWrite`.** On ESP32 core 3.x `analogWrite` claims an LEDC timer at ~1 kHz; if it runs first the servo shares that timer and spins continuously.
3. **Forward counts DOWN on the encoder.** The Pi takes `abs()` on every comparison, so the sign has been invisible for the whole project. Any new code comparing a *signed* distance must flip it.
4. **90 is not straight.** Measured two ways: the heading controller settles at 87.1 holding a straight line, and a reverse commanded at 90 curves left at 0.45 °/cm over 486 cm.
5. **NDOF gives a dead heading on this car.** The BNO055 in NDOF fuses the magnetometer, which never calibrates beside a motor and a LiPo — `mag` stays 0 and `orientation.x` reads a permanent `0.0`. Use **`OPERATION_MODE_IMUPLUS`** (accel + gyro, no mag) for relative heading. The gyro reaches `cal 3` about two seconds after you start reading it.
6. **Read the IMU while waiting for START.** A BNO055 read moments after `begin()` has not settled.
7. **999 means two different things** — "nothing in range" *and* "sensor errored" — and the driving logic reads it as an OPEN side, which is what triggers a corner. A flaky sensor invents corners.
8. **Stop `master.service` and `dashboard.service` before flashing**, or esptool dies mid‑write.
9. **`dashboard.py` owns the serial port.** `main.py` talks to the ESP32 *through it* over UDP 127.0.0.1:5005. **If dashboard.py is not running, the car will not move.**
10. **The ESP32 only sends `DATA` lines under `open_slave`.** Any other sketch → the dashboard correctly reports the ESP32 as silent. That is not a fault.
11. **The Pi throttles.** It sits at ~85 °C with no active cooling; `vcgencmd get_throttled` shows the ARM clock capped. No under‑voltage.

---

## 3. Parking exit

The car starts parked against one wall. **This now runs as the first phase of
the obstacle round itself** — it is no longer a separate sketch you flash and
run by hand. Press START once and the car parks out, squares up, and goes
straight into the race.

### Sequence

| Step | Action | **Ends on** |
|---|---|---|
| 0 | **LOOK** — the same wall reading that locks the lap direction | — |
| 1 | **TURN OUT** — full lock *away from the nearer wall*, forward | **IMU**: turned 90° |
| 2 | **STRAIGHT** — hold that heading with a P term | **ENCODER**: 80 cm |
| 3 | **BACK** — reverse, holding heading | **ENCODER**: 20 cm |
| 4 | **SQUARE UP** — opposite full lock | **IMU**: back to 0° |

**Direction rule.** Nearer the **left** wall → exit **right** *and* lap
**clockwise**. Nearer the **right** → exit left, lap anticlockwise. One reading
drives both, so the exit and the lap can never disagree.

### Parameters

All seven are live on the dashboard, so the exit can be retuned or switched off
at the track without a reflash.

| | Value |
|---|---|
| `park_enabled` | 1 |
| `park_turn_deg` | 90 |
| `park_forward_cm` | 80 |
| `park_back_cm` | 20 |
| `park_steer_deg` | 50 |
| `park_speed` | 90 PWM |
| `park_max_cm` (failsafe) | 400 |

### Rules that matter

- **Every step ends on a sensor, never a clock.** Angles on the IMU, distances
  on the encoder.
- **The swings stop on a threshold CROSSING, not inside a window.** The IMU is
  read about every 20 ms while the car turns, so it steps straight over any
  window — 86 then 97 — and once past it the error only grows while the
  steering stays hard over. That is what made the ESP sketch spin in circles.
- **Both swings are bounded by distance.** Past `park_max_cm` with the heading
  not arriving, the car abandons the exit and races anyway rather than turning
  on the spot.
- **Parking owns the car outright.** No corners, no pillars, no centring until
  it finishes.
- **Handover re-zeroes the heading target** to where the car actually points —
  it is square again, but displaced sideways from where it was parked.

## 4. Obstacle round — overall movement

Three behaviours, in strict priority order.

### Priority

1. **Going around a block** — once it starts, **nothing** interrupts it
2. **Corner turns**
3. **Lane centring** — only when no pillar stage is active

### 4.1 Lane centring (straights)

Copied verbatim from `final_open_round_working.ino`:

```
correction = headingError × 1.2 + wallCentering
```

One proportional term on heading, one on the walls, **no integral**. Both walls seen → balance them; one wall → hold `cruise_target_cm` off the outer one, chosen from the locked lap direction.

| | Value |
|---|---|
| `cruise_wall_k` | 1.6 |
| `cruise_target_cm` | 42 |
| `KP_HEADING_CRUISE` | 1.2 |
| valid wall reading | < 80 cm |

> The servo has 50° of authority either side of centre. At gain 1.6 an L10/R70 lane position asks 48° of it from the wall term alone. If the car weaves or scrubs, drop this gain first.

### 4.2 Corners

**Lap direction is decided once, before the car moves**, from the parking bay:
nearer the **left** wall → **clockwise**, right turns only. Nearer the **right** → anti‑clockwise, left turns only. It never changes afterwards. Deciding it per corner from whichever side looked open produced left turns on a clockwise track whenever a sensor dropped out.

| Step | Action | Ends on |
|---|---|---|
| 1 | drive forward | front ToF ≤ **37 cm** |
| 2 | **reverse arc** — wheels **40° the opposite way**, reversing | **IMU**: all but 35° of the turn done |
| 3 | **forward turn** onto the exact heading target | **IMU** |
| 4 | **reverse 40 cm** straight, holding heading on the gyro | **ENCODER** |

The reverse arc swings the nose toward the new heading *while* backing off the wall, so one manoeuvre buys clearance and does part of the turn. The heading target is absolute (previous + 90°), so rotation gained in the arc is banked, not wasted.

> That is **75 cm of reversing per corner**, all of it blind.

### 4.3 Going around a block

Green is passed on the car's **LEFT**, Red on its **RIGHT**.

| Stage | Action | Ends on |
|---|---|---|
| APPROACH | drive on, tracking the nearest pillar | trigger distance |
| BACKOFF | if closer than 35 cm, **reverse** to 35 cm | ENCODER |
| TURN_OUT | swing out | ENCODER |
| STRAIGHTEN | run past the pillar on heading hold, ToF ignored | ENCODER |
| RECENTER | swing back in | ENCODER |
| ALIGN | square up on the original heading | IMU, min forward run |

**The turn‑out length is computed from the pillar's pixel offset**, not a two‑value arc split:

```
sideways_cm = 31.15 + toward_px × 0.08
```

`toward_px` is signed *by dodge direction* — a Green further **left** needs more, one already drifting right needs less; Red mirrors. Latched **once**, at commit, because the pillar leaves frame as the car turns.

| | Value |
|---|---|
| trigger distance | 30 cm |
| back‑off target / max | 35 cm / 45 cm |
| run past pillar | Green 62 cm, Red 57 cm |
| swing back in | turn‑out + 3 cm (+3 more for Green) |

### Rules that matter

- **Nothing interrupts a dodge** — no corner, and no front reading however short. The front sensor sweeps across the pillar being dodged and reads short every time; aborting on it killed good dodges and left the car angled across the lane.
- **Only a pillar dead ahead may claim a short front reading.** The front ToF looks straight forward, so a pillar in the LEFT or RIGHT band cannot be what it is measuring — that reading belongs to a wall, and the corner takes it.
- **Camera and ToF must agree** within 25 cm before the ToF commits a dodge. Disagreement means they are looking at different objects.
- **The nearest pillar wins**, re‑evaluated every frame with a 20 cm margin so two at similar range cannot make it flip.
- **A pillar just passed is not a new one** — the car must travel 60 cm clear before adopting another.

---

## 5. Testing without the car

Fourteen suites in `obstacle_round/pi/tools/`, no hardware needed:

```bash
python3 tools/smoke_test.py          # every dodge stage + both corner paths
python3 tools/corner_test.py         # corners land on 90°
python3 tools/parking_test.py        # direction from the parking bay
python3 tools/priority_test.py       # nothing interrupts a dodge
python3 tools/backoff_test.py        # back off to a fixed distance
```

**Run them before every deploy.** They have caught real bugs that would otherwise have reached the car — including one where a fix silently disabled dodging entirely.

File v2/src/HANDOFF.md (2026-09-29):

# Handoff prompt

Copy everything below the line into a new AI session to bring it up to speed on this robot.

---

You're picking up work on our WRO 2026 Future Engineers robot (Team Yo_Error_404, "V2 bot").
Read all of this before touching anything.

──────
## How to work with me

- Keep replies SHORT: one short paragraph saying what changed, why, and what it does.
- **ESP Reflash Protocol:** if a change touches the ESP32 sketch, the reply must START with `(REFLASH NEEDED)` or `(no reflash)`. Better still, flash it yourself from the Pi over SSH and confirm you did.
- **Git Hygiene:** after EVERY code edit, commit AND push to GitHub (`origin main`) with a clear message, and update `CHANGELOG.md`. Keep the READMEs current.
- **No simulations:** build for the real physical robot and test on the real bot/Pi.
- **Hard Safety Limits:**
  - Motor speed capped at ±170 PWM, forward and reverse, enforced in both the Pi code and the ESP32 firmware.
  - Steering servo clamped to 30°..140° (mechanical stops are 28°..142°; 90° = straight, >90° = right, <90° = left).
- **Deployment:** deploy to the Pi yourself over SSH. Don't hand me terminal commands to paste.
- **Network Resilience:** the Pi is at `pi@error404.local` / `192.168.1.53`. It drops off Wi-Fi when the battery is swapped or power-cycled, and it has browned out repeatedly under motor load — wait and retry rather than assuming failure.
- **Step-by-Step Delivery:** small verified steps with my green light before each phase, not massive unchecked rewrites.
- **Verify, don't assume.** Measure on the car and show me the numbers. Several long debugging detours in this project came from trusting a value instead of testing it.

──────
## Hardware

- **Master:** Raspberry Pi 5, `pi@error404.local` (`192.168.1.53`), key auth, sudo password `pi`. Raspberry Pi OS 64-bit Bookworm.
- **Slave:** ESP32-C3 Super Mini over USB (`/dev/serial/by-id/usb-Espressif_*` → `/dev/ttyACM0`).
  - **Drive motor:** MD10112 — **IN1 = GPIO0 (PWM)**, **IN2 = GPIO1 (DIR, HIGH = forward)**.
  - **Steering:** DS3218 servo on GPIO6, 50 Hz, 500–2400 µs.
  - **Sensors:** TCA9548A mux (0x70) on SDA GPIO8 / SCL GPIO9 —
    **ch0 front ToF, ch1 LEFT ToF, ch2 RIGHT ToF** (left/right were physically swapped on the car, the firmware compensates), ch3 rear ToF, ch4 BNO055 IMU (NDOF, yaw 0–359.9°, clockwise positive).
  - **Wheel encoder:** GPIO4 channel A (interrupt), GPIO5 channel B (direction).
  - START button GPIO10 (pull-up); 16× WS2812B on GPIO7.
- **Camera:** Pi Camera Module 3 Wide, 1024×576 RGB888 @ 30 fps.
  **CURRENTLY NOT DETECTED** — `rpicam-hello --list-cameras` reports "No cameras available", no overlay loads, and nothing answers at I²C 0x1a. That is below the software layer, so it is a ribbon cable, the module, or the CSI port. **With no camera there is no pillar detection at all.**

──────
## Repository

`github.com/BMWareSPEEDY/wro_fe_26_codes` — everything is committed and pushed.

| Path | What it is |
|---|---|
| `open_round/working_open_round/` | **The working open round.** Fully standalone: the ESP32 drives the whole round with no Pi. Also streams telemetry so the dashboard can display it when the Pi happens to be on. |
| `open_round/Working_Open_Round_V2_FE/` | The original proven open-round sketch. Do not modify. |
| `obstacle_round/esp/open_slave/` | Pure slave firmware: streams sensors, applies the Pi's commands, 500 ms watchdog. **Has no driving logic — useless without the Pi.** |
| `obstacle_round/pi/` | Pi master: `main.py` (control), `dashboard.py` (web UI + serial relay), `vision.py` (YOLO), `config.py`, `params.json`. |
| `obstacle_round/esp/tick_m_calculate/` | Calibration: drives 3 s, reports encoder ticks. Instructions in the sketch header. |
| `obstacle_round/esp/dir_probe/` | Diagnostic: drives every PWM/DIR pin combination and reports signed encoder movement. |
| `obstacle_round/esp/motor_stop/` | Safety: holds the motor off. Flash to make the car safe fast. |
| `parking_exit/` | Stand-alone parking exit test. |
| `pi_setup/` | `deploy.sh` and the systemd units. |

──────
## Two ways the car can run — know which one you're in

**1. Standalone open round** (`working_open_round` flashed)
The ESP32 does everything. Press START, it drives 12 corners, locks lap direction at the first, then a 3 s finish push. **The Pi is not required.** It still streams `DATA,...` at 50 Hz, so if the Pi is on the dashboard shows live values; if the Pi is off the car is unaffected. Writes are skipped when the USB buffer is full, so nothing can stall the control loop.

**2. Obstacle round** (`open_slave` flashed + Pi services running)
`open_slave` has zero driving logic. `dashboard.py` is the ONLY process that opens the serial port, and `main.py` talks to the ESP32 *through it* over UDP on 127.0.0.1:5005. **So `dashboard.py` must be running or the car will not move**, regardless of whether anyone is looking at the web page. Without a camera this degrades to the open round — corners only, no pillar dodging.

──────
## Running it

```bash
ssh pi@192.168.1.53

# services (both enabled at boot)
sudo systemctl status  dashboard.service master.service
sudo systemctl restart dashboard.service master.service
journalctl -u master.service -f          # watch decisions live

# dashboard
#   http://192.168.1.53:8080/   or   http://error404.local:8080/
```

Each run writes a CSV to `~/obstacle_round/logs/run_<timestamp>.csv` with per-tick sensor values, stage, decision, speed and steering. **Read the CSV before theorising** — it has caught several bugs that the live log hid.

### Flashing the ESP32

`arduino-cli` is installed **on the Pi** at `~/bin/arduino-cli`, with the esp32 core and the needed libraries. Sketches are staged in `~/sketches/`. Compile ~45 s, flash ~15 s.

```bash
ssh pi@192.168.1.53
export PATH=$HOME/bin:$PATH
cd ~/sketches
arduino-cli compile --fqbn esp32:esp32:esp32c3:CDCOnBoot=cdc --output-dir build_x <sketch>

sudo systemctl stop master.service dashboard.service     # they own the serial port
cp build_x/<sketch>.ino.merged.bin ~/esp_flash/
~/esp_flash/venv/bin/esptool --chip esp32c3 -p /dev/serial/by-id/usb-Espressif* \
    write-flash 0x0 ~/esp_flash/<sketch>.ino.merged.bin
sudo systemctl start dashboard.service master.service
```

**Stopping the services first is not optional** — `dashboard.py` holds `/dev/ttyACM0` and esptool fails mid-write otherwise. arduino-cli conveniently emits a single `.merged.bin` that drops straight into that command.

──────
## Tuning

`params.json` on the Pi, with live sliders on the dashboard (drag, then **Save to Disk** to persist):
`pillar_trigger_dist_cm`, `pillar_steer_left`/`right`, `turn_hold_pct`, `dodge_short_cm`, `dodge_long_cm`, `dodge_return_extra_cm`, `corner_steer_deg`, `front_turn_cm`, `recenter_target_cm`, `recenter_k`, `pillar_focal_px`.

Fixed constants live in `obstacle_round/pi/config.py`.

──────
## Hard-won gotchas — each of these cost hours

- **Never leave GPIO0 or GPIO1 as an input.** IN1 is the motor driver's PWM input; a pull-up on it reads as 100% duty and the car drives off at full speed with no code commanding it. Set them `OUTPUT` and `LOW` as the first statements in `setup()`.
- **Attach the servo before the first `analogWrite`.** On ESP32 core 3.x `analogWrite` claims an LEDC timer at ~1 kHz; if it runs first, `ESP32Servo` shares that timer instead of getting a clean 50 Hz one and the servo spins continuously.
- **Check PWM and DIR are on the pins you think.** They were swapped in firmware for weeks. The symptom was bizarre: full speed regardless of the commanded value, reverse producing exactly zero movement, and the car appearing not to respond to speed changes. `esp/dir_probe` diagnoses it in 30 seconds.
- **999 means two different things.** The firmware reports 999 both for "nothing in range" and "the sensor errored", and the driving logic reads 999 as an OPEN side — which is what triggers a corner. A flaky sensor invents corners. Measure the dropout rate before trusting a side reading.
- **Stop the services before flashing**, or esptool dies mid-write.
- **The Pi browns out under motor load.** It has rebooted mid-command many times. If SSH dies during a drive, that's why — wait and retry.
- **Re-measure `TICKS_PER_METER` after any wheel, gearing or encoder change** with `tick_m_calculate`. It was wrong by 46% at one point, so every distance the car drove was 46% longer than its label.
- The BNO055 needs a figure-eight to calibrate. Heading hold drifts until the `cal` values come off zero, and every corner targets an absolute heading.

──────
## State right now

- `working_open_round` is the current open-round firmware — standalone, with telemetry.
- The obstacle round's Pi code is at the last known-good state: turn at 45 cm, encoder-measured dodge legs, no reverse manoeuvres.
- **Reverse is not usable** on the current firmware pin assignment, so nothing that drives the motor backwards will work.
- **The camera is undetected**, so there is no pillar detection.

## What's left to build

1. Get the camera detected again — almost certainly the ribbon cable — and confirm pillar detection returns.
2. Lane centring on the straights. Currently just heading hold with a ±20° ToF nudge, so the car drifts into walls between corners. The proven logic is in `Working_Open_Round_V2_FE`, but its constants assume the real WRO corridor width and saturate the steering on a narrow test surface.
3. Multi-obstacle chaining across all four sections, once vision is back.

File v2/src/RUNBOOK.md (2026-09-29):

# Competition runbook — no Wi-Fi, no laptop help

Everything you need on the day, assuming there is no network at the venue and
nobody can SSH in from outside. Commands marked **UNTESTED** have not been run
on this Pi — try them at home before you travel.

Pi login: `pi` / sudo password `pi`. The Pi is called `ERROR404`.

---

## 1. Getting a terminal on the Pi with no Wi-Fi

Three ways, best first.

### a) The Pi makes its own hotspot, laptop joins it — **tested 2026-09-26**

Already set up on ERROR404 (NetworkManager profile `Hotspot`: SSID
**ERROR404**, password `wro2026team`, 2.4 GHz ch 6, Pi at 10.42.0.1). It is a
**fallback**: autoconnect priority -10, below every saved Wi-Fi, so at boot the
Pi joins a known network if one is in range and only starts the hotspot when
none is. Once on the hotspot it stays there until reboot or you switch.

Join Wi-Fi **ERROR404** from the laptop/phone, then:

```bash
ssh pi@10.42.0.1                 # NetworkManager's shared-mode address
# dashboard: http://10.42.0.1:8080/
```

Switch by hand (from a Pi terminal; your SSH drops when wlan0 changes mode):

```bash
sudo nmcli connection up Hotspot           # force the hotspot now
sudo nmcli connection up Testing           # back to the home Wi-Fi
sudo nmcli connection modify Hotspot connection.autoconnect no   # disable the fallback
nmcli connection show                      # list every saved connection
```

Recreate it from scratch if the profile is ever lost:

```bash
sudo nmcli device wifi hotspot ifname wlan0 con-name Hotspot ssid ERROR404 password wro2026team
sudo nmcli connection modify Hotspot 802-11-wireless.channel 6 ipv4.addresses 10.42.0.1/24 \
     connection.autoconnect yes connection.autoconnect-priority -10
```

⚠ The Pi has one radio: hotspot and home Wi-Fi never run at the same time.
`wro-radio.service` still kills Wi-Fi entirely when /boot/firmware/COMPETITION exists.

### b) Phone hotspot, both devices on it

Add the phone's hotspot to the Pi **before you travel** (it remembers it):

```bash
sudo nmcli device wifi connect "<HOTSPOT SSID>" password "<PASSWORD>"
nmcli -f NAME,AUTOCONNECT connection show
```

Then find the Pi from the laptop:

```bash
ssh pi@error404.local            # usually works
dns-sd -G v4v6 ERROR404.local    # if not: prints its current address (Mac)
```

⚠ Some phone hotspots isolate clients, so the laptop can see the network but
not the Pi. If that happens, use (a) or (c).

### c) Ethernet cable, laptop to Pi

No router needed — link-local addressing does it:

```bash
ssh pi@error404.local
```

On a Mac, set the Ethernet adapter to "Using DHCP" and give it a moment.

### d) Nothing works: keyboard + monitor

Micro-HDMI to the Pi, USB keyboard, log in as `pi`. Everything below works the
same; the dashboard is then `http://localhost:8080/`.

---

## 2. Services

`dashboard.service` owns the ESP32 serial port and the camera, and relays for
`main.py`. `master.service` runs `main.py`, the obstacle round. **If the
dashboard is not running, the car cannot move**, even if you never open the
web page.

```bash
systemctl is-active dashboard.service master.service     # are they up?
sudo systemctl restart dashboard.service master.service  # restart both
sudo systemctl stop master.service                       # stop driving, keep the dashboard
sudo systemctl stop master.service dashboard.service     # free the serial port (for flashing)
sudo systemctl start dashboard.service master.service
journalctl -u master.service -f                          # live log, Ctrl+C to leave
journalctl -u master.service -b --no-pager | tail -40    # this boot
```

Both start at boot on their own. The dashboard waits up to 30 s for the camera
first, so give it that long after power-on.

---

## 3. Which firmware is on the ESP32?

| Round | Firmware | Telemetry rate | Who drives |
|---|---|---|---|
| Open | `working_open_round` | ~8 Hz | the ESP32 alone, Pi ignored |
| Obstacle | `open_slave` | ~50 Hz | the Pi (`main.py`) |

Check without opening anything:

```bash
curl -s localhost:8080/api/state | python3 -c "import sys,json;s=json.load(sys.stdin);print(round(s['rate_hz'],1),'Hz')"
```

~8 Hz means the open round is loaded; ~50 Hz means the slave is.

---

## 4. Flashing the ESP32

### The easy way: the three buttons on the dashboard

The **Round** card has one button per round. Pressing one does everything:
compiles the sketch, hands the serial port to esptool, flashes the ESP32,
takes the port back, then starts the right Pi service and enables it at boot —
so the car comes back up in the same round after a power cut. About 25 s, and
the log under the buttons shows each step.

| Button | ESP32 firmware | Pi side | Telemetry |
|---|---|---|---|
| Open Round | `working_open_round` | nothing drives | ~3–8 Hz |
| Obstacle Round | `open_slave` | `master.service` | ~50 Hz |
| Parking test | `open_slave` | `parking.service` | ~50 Hz |

Open round is the default the car boots into: no parking, no `main.py`. A real
round never runs the parking service — that button is for testing the exit on
its own.

### By hand (all from the Pi)

Always stop the services first — they hold the serial port and the flash fails
mid-write otherwise.

```bash
export PATH=$HOME/bin:$PATH
cd ~/sketches
sudo systemctl stop master.service dashboard.service
```

**Open round** (ESP drives everything):

```bash
arduino-cli compile --fqbn esp32:esp32:esp32c3:CDCOnBoot=cdc --output-dir build_wor working_open_round
cp build_wor/working_open_round.ino.merged.bin ~/esp_flash/
~/esp_flash/venv/bin/esptool --chip esp32c3 -p /dev/serial/by-id/usb-Espressif* -b 460800 \
    write-flash 0x0 ~/esp_flash/working_open_round.ino.merged.bin
```

**Obstacle round** (Pi drives):

```bash
arduino-cli compile --fqbn esp32:esp32:esp32c3:CDCOnBoot=cdc --output-dir build_slave open_slave
cp build_slave/open_slave.ino.merged.bin ~/esp_flash/
~/esp_flash/venv/bin/esptool --chip esp32c3 -p /dev/serial/by-id/usb-Espressif* -b 460800 \
    write-flash 0x0 ~/esp_flash/open_slave.ino.merged.bin
```

**Make the car safe in a hurry** (motor held off, nothing else):

```bash
arduino-cli compile --fqbn esp32:esp32:esp32c3:CDCOnBoot=cdc --output-dir build_stop motor_stop
cp build_stop/motor_stop.ino.merged.bin ~/esp_flash/
~/esp_flash/venv/bin/esptool --chip esp32c3 -p /dev/serial/by-id/usb-Espressif* -b 460800 \
    write-flash 0x0 ~/esp_flash/motor_stop.ino.merged.bin
```

Then bring the services back:

```bash
sudo systemctl start dashboard.service master.service
```

Flashing takes about 10 s. "Hash of data verified" means it worked.

---

## 5. Running a round

**Open round**: flash `working_open_round`, then just press START on the car.
The Pi is not involved. Corners are the smooth drift turn followed by a 90 cm
reverse.

**Obstacle round**: flash `open_slave`, make sure both services are up, then
press START. The button is a toggle — press again to stop, again to start a
fresh run. One run per power-up unless you press it again.

Before a scored run:

- Give the BNO055 a figure-eight until the dashboard calibration shows 3s.
  Every corner targets an absolute heading.
- Check the dashboard shows ToF values and the camera feed.
- `journalctl -u master.service -f` in a spare terminal tells you what it is
  deciding, live.

---

## 6. Tuning on the day

Sliders on the dashboard apply instantly; **Save to Disk** makes them survive a
restart. Without SSH you can still do all of it from a phone browser on the
hotspot.

From a terminal instead:

```bash
cat ~/obstacle_round/params.json                      # what is saved
python3 - <<'EOF'
import json; f="/home/pi/obstacle_round/params.json"
p=json.load(open(f)); p["post_turn_reverse_cm"]=90    # change what you need
json.dump(p,open(f,"w"),indent=2); print(p)
EOF
sudo systemctl restart master.service
```

The ones you are most likely to touch:

| Param | What it does |
|---|---|
| `post_turn_reverse_cm` | how far back after each corner |
| `corner_steer_deg` | corner steering cap — bigger is tighter |
| `front_turn_cm` | how close to the wall before turning |
| `pillar_trigger_dist_cm` | when the dodge commits |
| `dodge_short_cm` / `dodge_long_cm` | dodge leg lengths, normal and wide arc |
| `lap_direction` | **-1 anti-clockwise, 0 auto, +1 clockwise** — set it and the car never guesses |

---

## 7. Rule 11.10 — radios off for a scored run

```bash
sudo touch /boot/firmware/COMPETITION && sudo reboot     # Wi-Fi and Bluetooth off at boot
sudo rm /boot/firmware/COMPETITION && sudo reboot        # back to normal
```

With that file present the web dashboard does not start (the relay, camera and
YOLO still do, so the car drives normally) — and you cannot SSH in either, so
do your tuning first.

---

## 8. When something is wrong

```bash
# is anything crashing?
journalctl -u master.service -b --no-pager | grep -icE "traceback|AttributeError"
# is the ESP talking at all?
ls /dev/serial/by-id/
curl -s localhost:8080/api/state | python3 -m json.tool | head -20
# does the code still behave? (no hardware needed, ~20 s)
cd ~/obstacle_round && python3 tools/smoke_test.py
# last run, second by second
ls -t ~/obstacle_round/logs/run_*.csv | head -3
```

**ESP silent (0 Hz, no DATA lines)**: usually a ToF sensor stuck after a reset.
Power-cycle the whole car — a chip reset alone does not clear it.

**Camera missing**: it is only probed at boot. Reseat the USB camera and
reboot; `rpicam-hello --list-cameras` is for the CSI camera, which is dead on
this car.

**Put the code back to a known state**:

```bash
cd ~/wro_fe_26_codes && git log --oneline -10        # on the laptop
git checkout <commit> -- obstacle_round/             # then redeploy
ls ~/backups/                                        # on the Pi: dated copies
```

---

## 9. Before you leave home

- [ ] Pi hotspot: joined from laptop and phone (Pi side tested 2026-09-26)
- [ ] Phone hotspot saved on the Pi as a second option
- [ ] Ethernet cable packed, link-local SSH tested
- [ ] Both firmwares compiled on the Pi at least once (so `~/sketches/build_*`
      exists and a flash is 10 s, not a first-time toolchain download)
- [ ] `motor_stop` compiled, for the panic case
- [ ] Spare battery charged, and a spare USB cable for the ESP32
- [ ] `params.json` saved with the values you actually want

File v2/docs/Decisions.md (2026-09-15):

# Design Decisions (`docs/Decisions.md`)

This is a comprehensive record of the architectural choices, component selections, design iterations, and engineering trade-offs made while constructing the **Yo_Error_404** autonomous vehicle for the WRO Future Engineers 2026 competition.

---

## 1. 10 June — Power Distribution & Isolated 3-Domain Architecture

**Decision.** Use an isolated 3-domain power architecture with dual buck converters and a central power distribution board instead of a single shared rail.

**Why.** Initial testing with a single shared power rail revealed severe system instability: heavy current spikes drawn by the steering servo under load induced voltage drops on the logic rail, dragging it below 4.75V and triggering reboots on the Raspberry Pi 5. Furthermore, motor PWM noise induced signal corruption on the shared I2C bus, causing IMU heading drift.
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

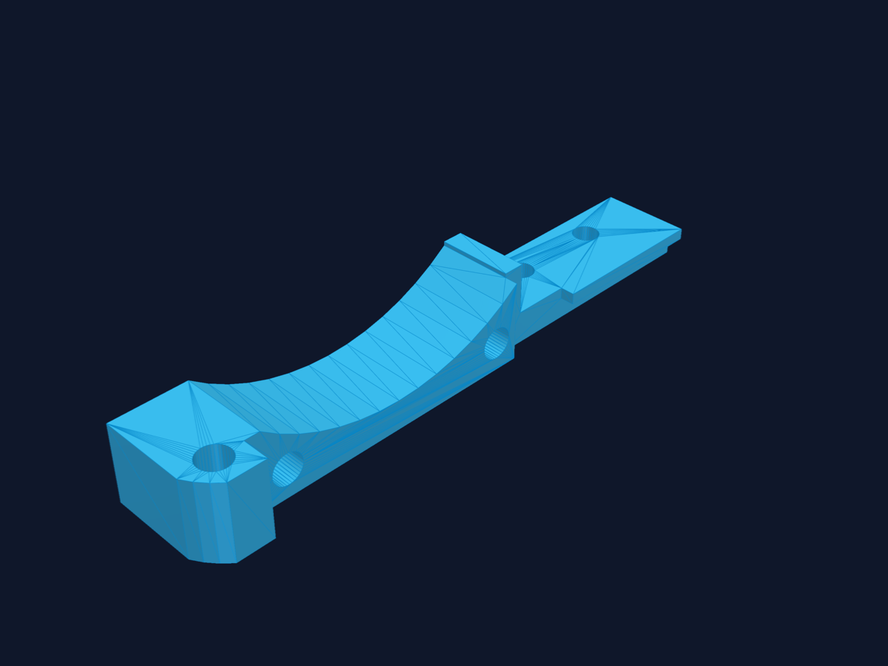
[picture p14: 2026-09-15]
v2/models/renders/Side_Bearing_Plate_Chassis_Fixture.png

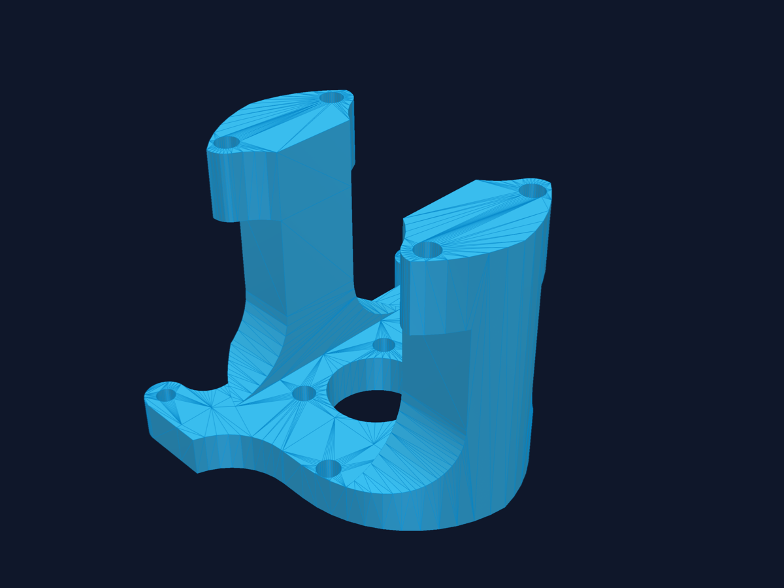
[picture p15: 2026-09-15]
v2/models/renders/JGB37_DC_Motor_Chassis_Mount.png

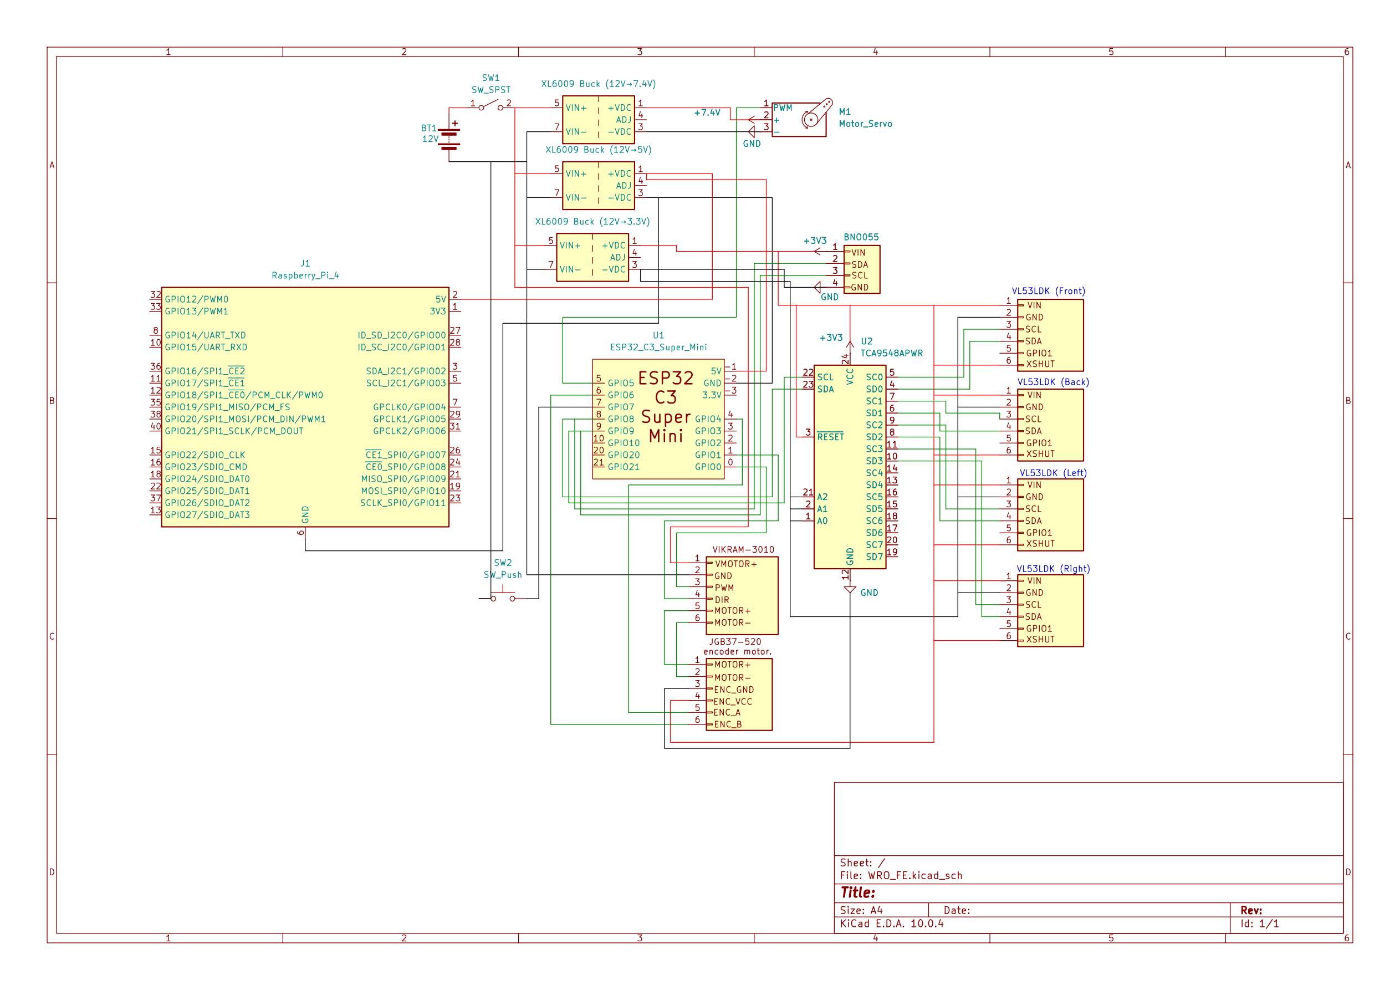
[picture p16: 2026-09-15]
v2/schemes/obstacle_round/schematic.png

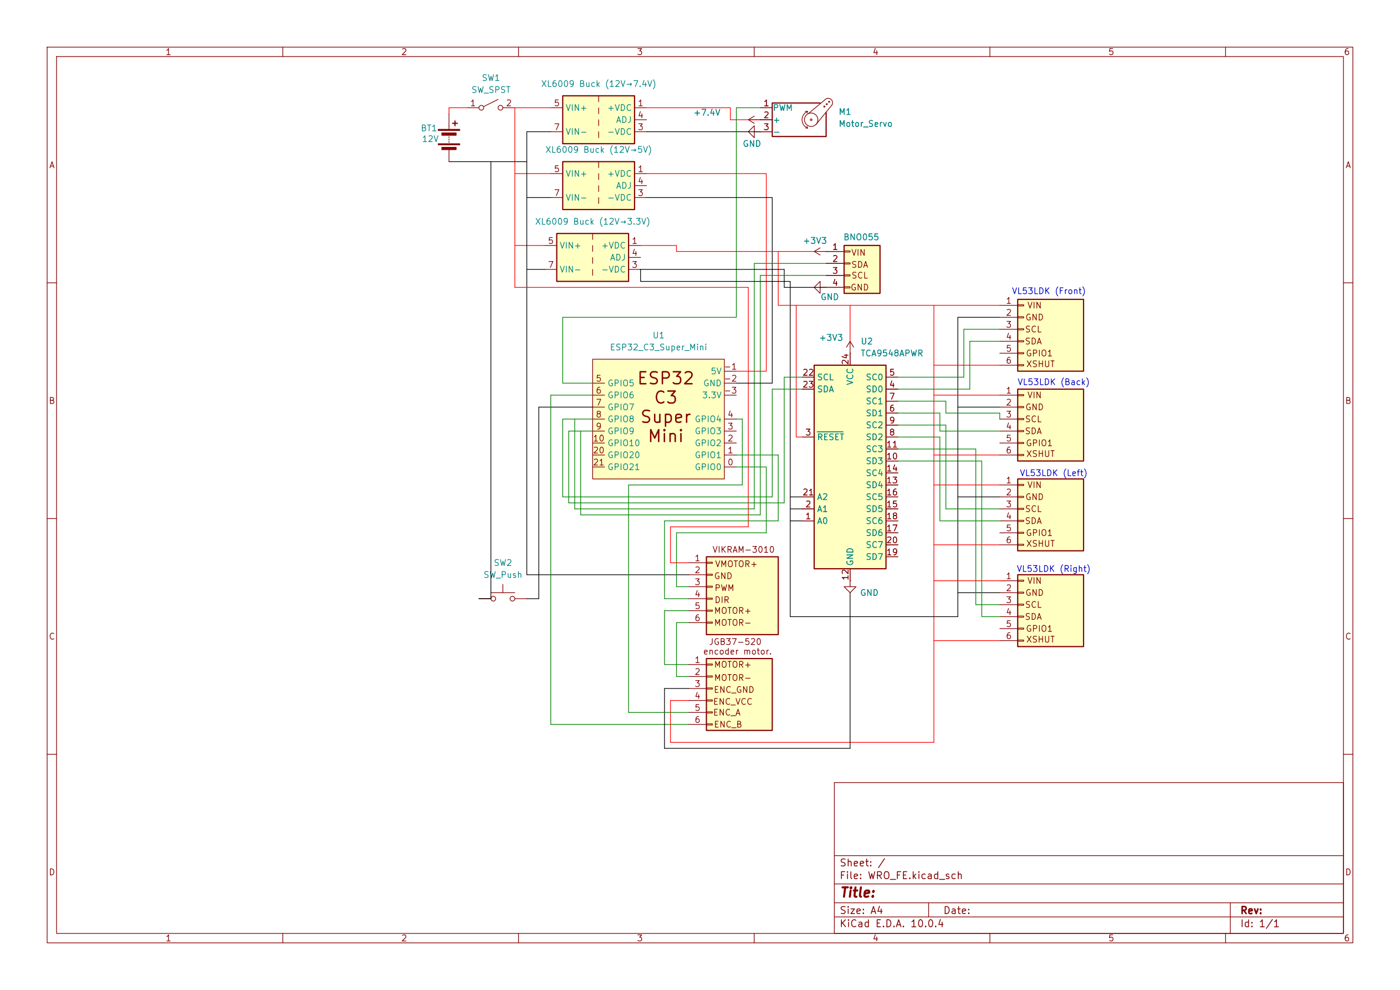
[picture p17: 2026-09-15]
v2/schemes/open_round/schematic.png

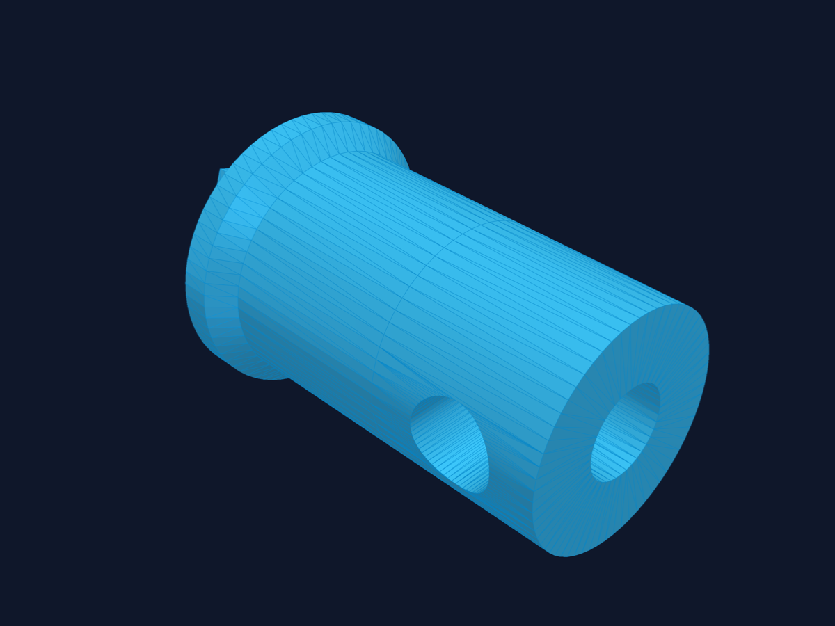
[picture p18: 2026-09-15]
v2/models/renders/Rear_Axle_CarbonRod_Drive_Coupler.png

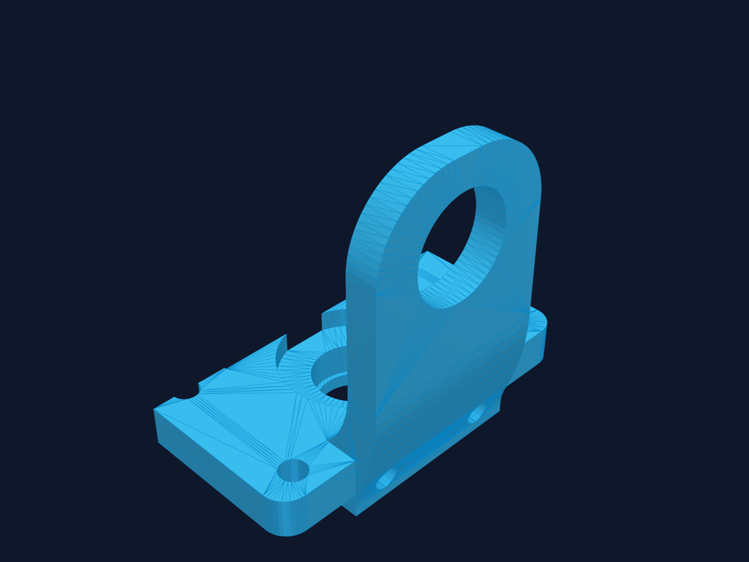
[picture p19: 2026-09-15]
v2/models/renders/Rear_Differential_Split_Holder_Part2_V3.png

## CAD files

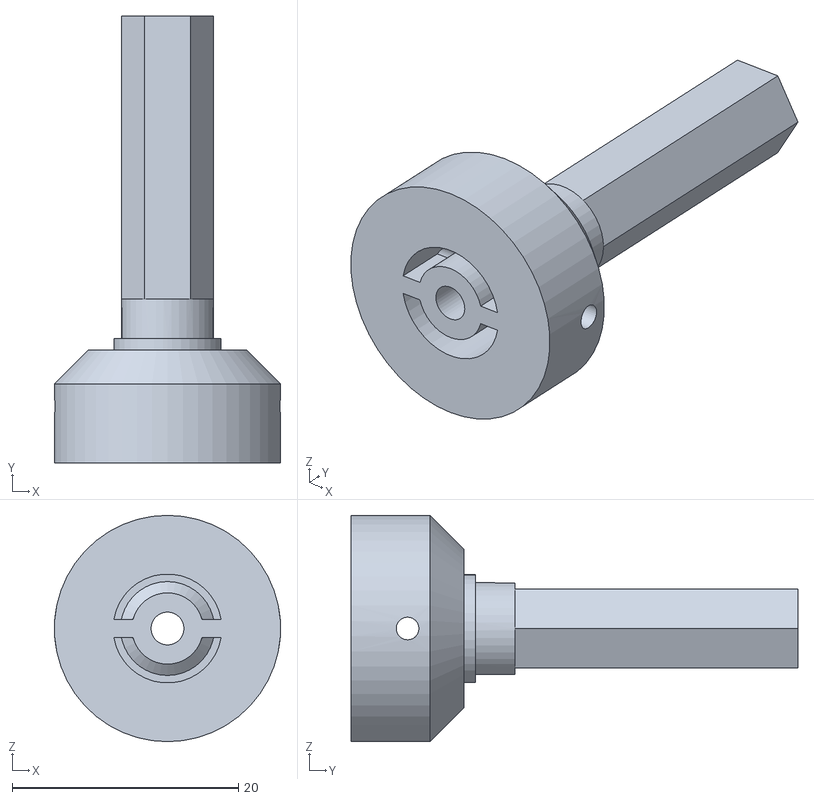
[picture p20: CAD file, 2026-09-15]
v2/models/Rear_Drive_Wheel_Hub_Assembly.stl
20.0 x 39.5 x 20.0

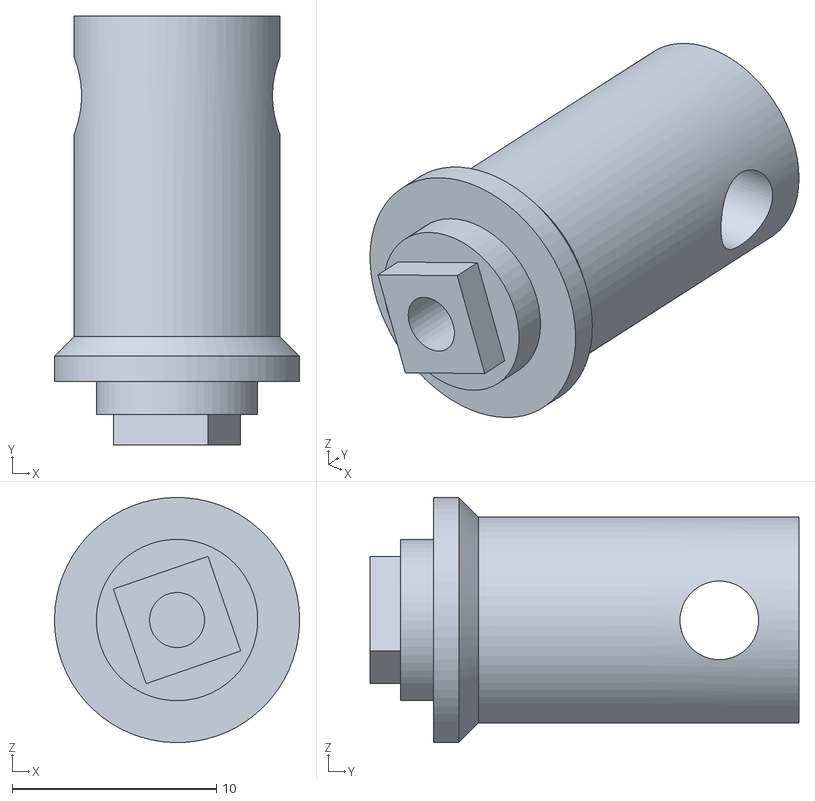
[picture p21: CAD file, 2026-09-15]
v2/models/Front_Rear_Differential_Assembly_V3.stl
12.0 x 21.0 x 12.0

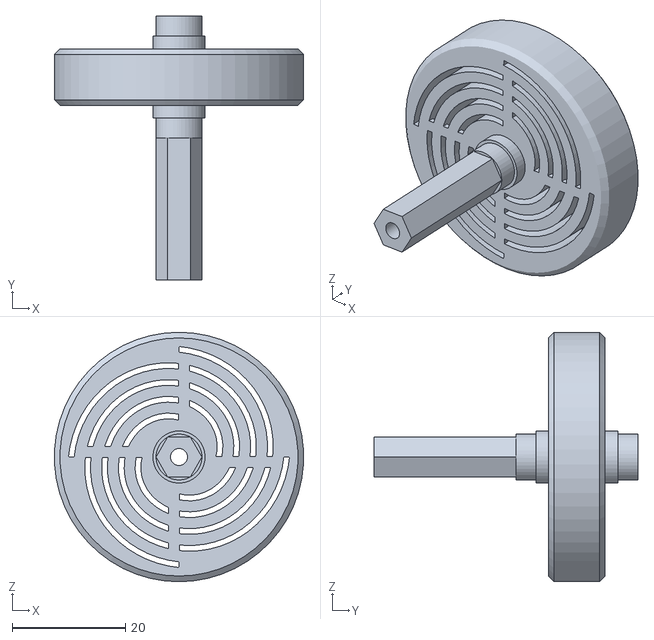
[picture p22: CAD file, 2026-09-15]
v2/models/Front_Wheel_Rim_Hub_Assembly.stl
43.9 x 46.5 x 44.0

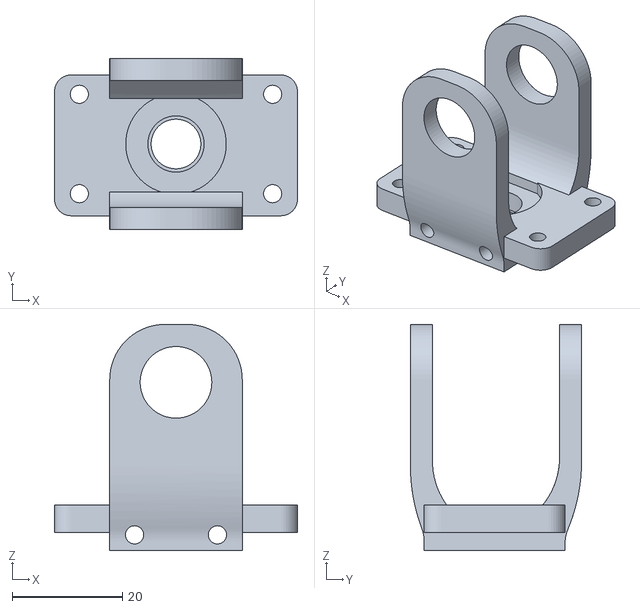
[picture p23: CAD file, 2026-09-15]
v2/models/Rear_Differential_Setup_Holder_V2.stl
44.0 x 31.0 x 41.0

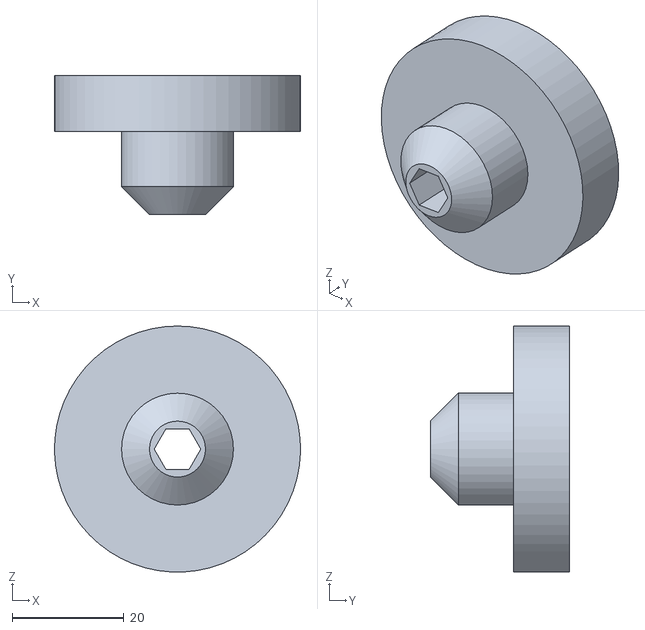
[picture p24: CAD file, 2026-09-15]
v2/models/Front_Wheel_HighTraction_Hub_V2.stl
44.0 x 24.9 x 44.0

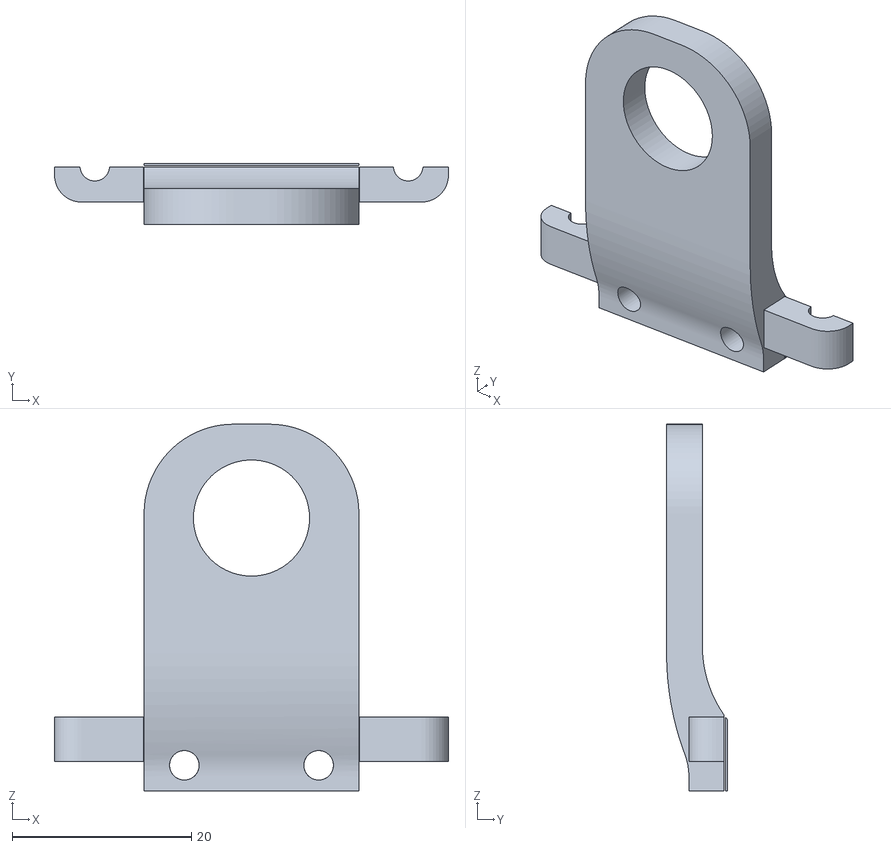
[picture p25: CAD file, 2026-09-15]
v2/models/Rear_Differential_Split_Housing_V3.stl
44.0 x 6.80 x 41.0

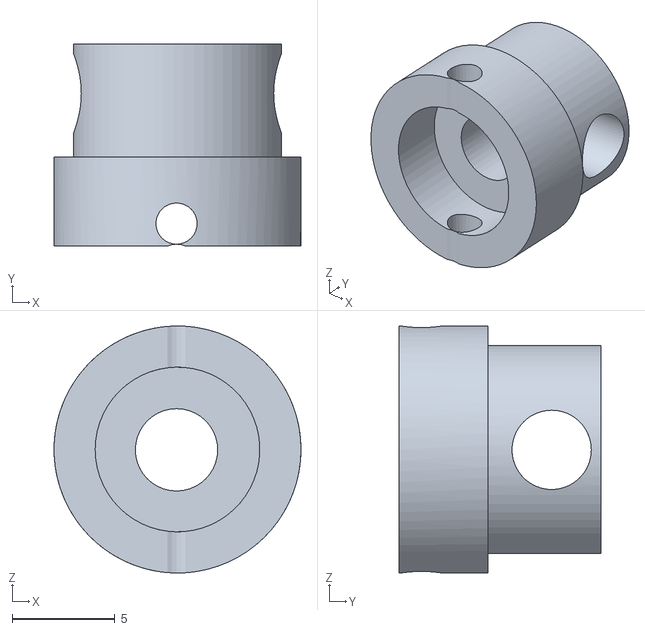
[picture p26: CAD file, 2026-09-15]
v2/models/Carbon_Rod_Differential_Coupler_V2.stl
12.0 x 9.82 x 12.0

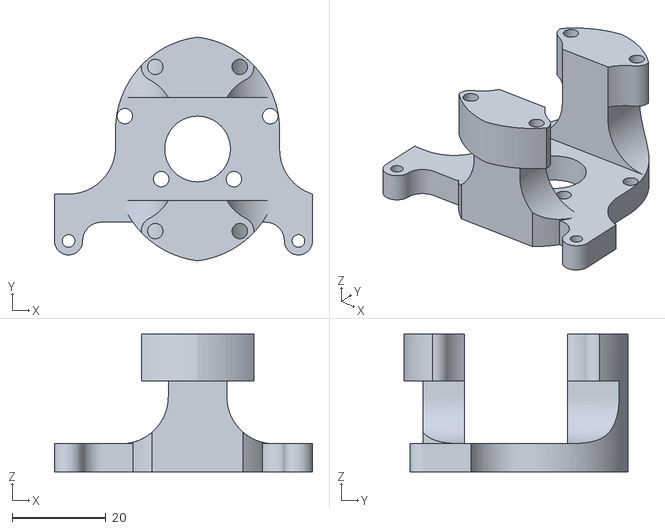
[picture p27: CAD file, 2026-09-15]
v2/models/HighTorque_DC_Motor_Mount_V2.stl
55.0 x 47.7 x 29.3

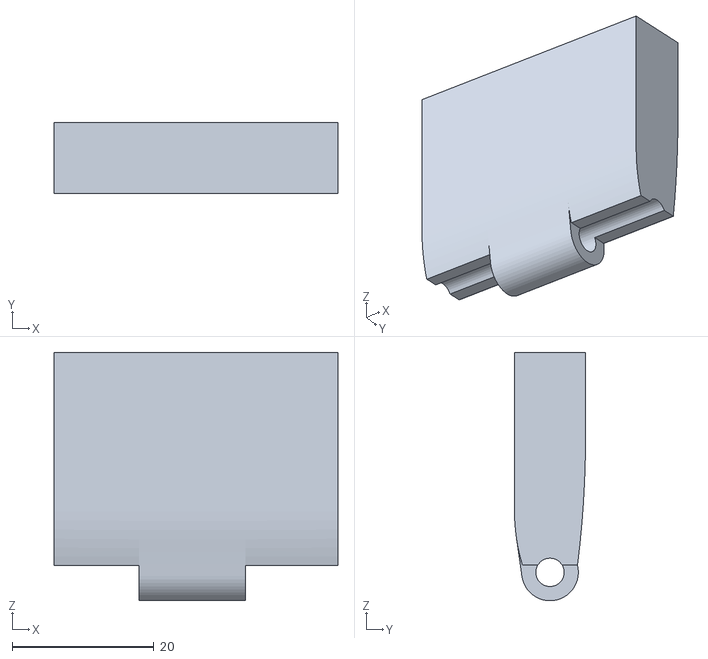
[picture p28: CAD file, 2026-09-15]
v2/models/Front_Vision_Camera_Module3_Bracket.stl
40.0 x 10.0 x 35.0

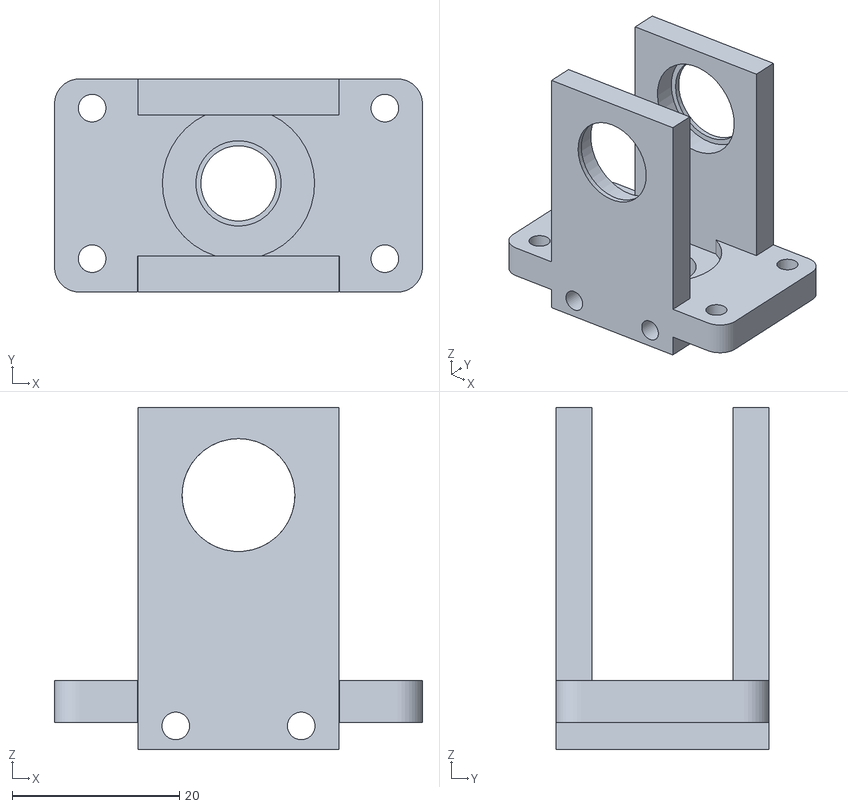
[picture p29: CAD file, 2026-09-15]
v2/models/Rear_Differential_Transmission_Gear_Mount.stl
44.0 x 25.5 x 41.0

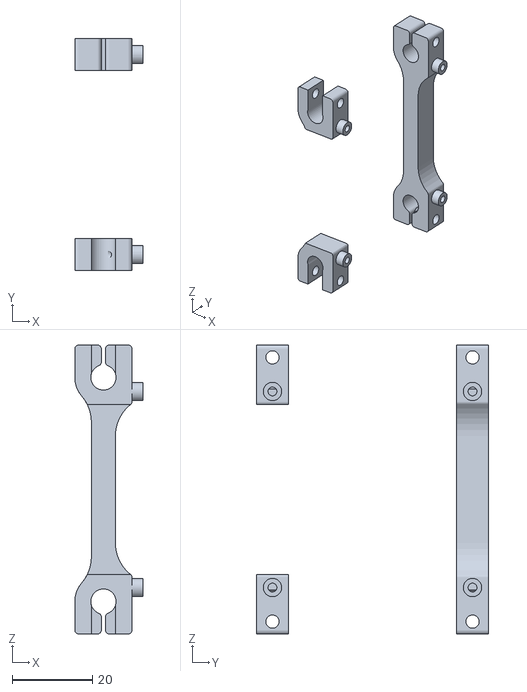
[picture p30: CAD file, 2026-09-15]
v2/models/Compute_Deck_RaspberryPi5_Mounting_Tray.stl
17.1 x 58.0 x 72.2

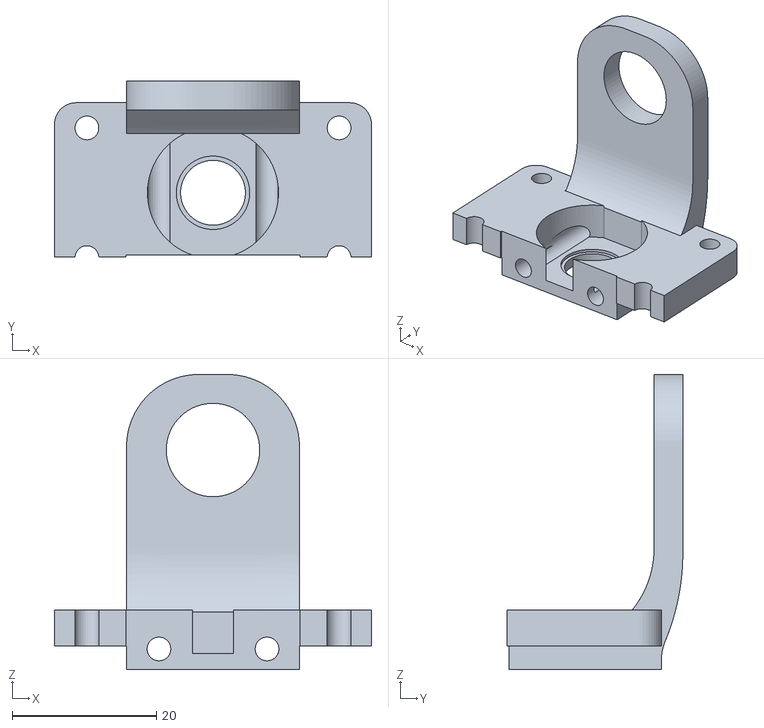
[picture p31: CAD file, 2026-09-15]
v2/models/Rear_Differential_Housing_Holder_V4.stl
44.0 x 24.4 x 41.0

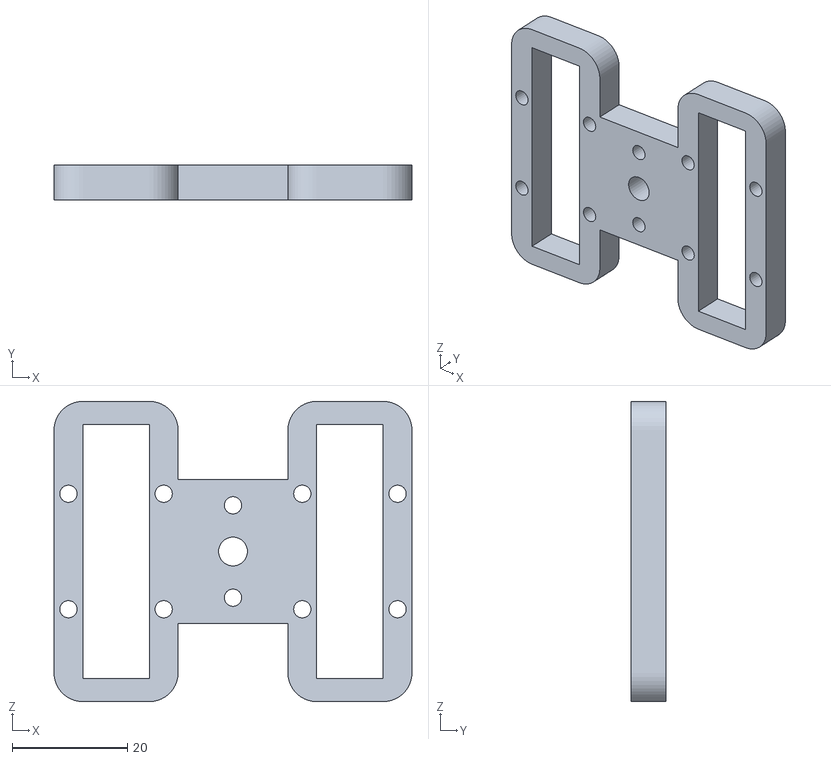
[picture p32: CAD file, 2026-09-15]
v2/models/Front_Axle_Structural_Support_Bracket.stl
62.0 x 6.00 x 52.0

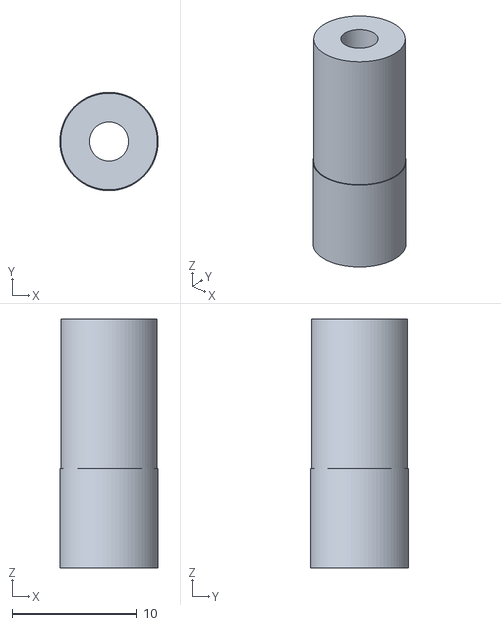
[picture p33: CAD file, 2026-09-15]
v2/models/Steering_Servo_Horn_Interface_Coupler.stl
7.90 x 7.89 x 20.0

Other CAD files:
v2/models/Side_Bearing_Plate_Chassis_Fixture.stl
v2/models/Metal_Differential_Carbon_Axle_Interface.stl
v2/models/Metal_Differential_Input_Drive_Coupler.stl
v2/models/Side_Axle_Aluminum_Bearing_Block_Pair.stl
v1/models/Chassis_bottom_view.stl
v1/models/Chassis_top_view.stl
v1/models/Ultrasonic_Sensor_Mount.stl
v1/models/drive_motor_holder.stl
v1/models/drive_shaft.stl
v1/models/pi_camera_3_mount.stl
v1/models/pi_camera_3_mount_2.stl
v1/models/pi_camera_3_mount_3.stl
v2/models/Elevated_Vision_Mast_Camera_Housing.stl
v2/models/Front_Ackerman_Steering_Knuckle_Hub.stl
v2/models/Front_Axle_6x12_Ball_Bearing_Retainer.stl
v2/models/JGB37_DC_Motor_Chassis_Mount.stl
v2/models/Metal_Differential_Setup_Holder_V5.stl
v2/models/Metal_Differential_Split_Holder_V5.stl
v2/models/Primary_Modular_Chassis_Baseplate_6mm.stl
v2/models/Propulsion_DC_Motor_Shaft_Coupler.stl
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

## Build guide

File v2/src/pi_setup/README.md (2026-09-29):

# Pi setup (copied from the Pi on 2026-09-19)

| File | Installed at | Purpose |
|---|---|---|
| `dashboard.service` | `/etc/systemd/system/dashboard.service` | Starts **`dashboard.py`** at boot and keeps it running whether `main.py` runs or not. It owns the ESP32 port and the camera, serves `http://error404.local:8080/`, and relays for `main.py`. In competition mode the web page and camera are off but the relay still runs. |
| `master.service` | `/etc/systemd/system/master.service` | Starts **`/home/pi/obstacle_round/main.py`** (the Pi master) at boot (after `dashboard.service`) and restarts it if it exits. It keeps only the 20 newest run CSVs. Stopping it (`sudo systemctl stop master.service`) leaves the dashboard up. The previous unit, which ran the V1 `/home/pi/codes/master.py`, is saved on the Pi as `master.service.bak.v1_codes_master`. |
| `deploy.sh` | (run on the laptop) | Deletes the old obstacle code from the Pi (`~/obstacle_round` code and `~/codes`) after saving a tarball in `~/scrapped_obstacle_*.tar.gz`, and keeps the dataset, runs and models. Then it copies `obstacle_round/pi/` to `~/obstacle_round/`, installs both services, and enables and restarts them. |
| `wro-radio.service` | `/etc/systemd/system/wro-radio.service` | Runs `wro-radio.sh` once at boot |
| `wro-radio.sh` | `/usr/local/bin/wro-radio.sh` | **Rule 11.10.** If `/boot/firmware/COMPETITION` exists, it blocks Wi-Fi and Bluetooth with `rfkill`. |

Race-day flow: power on, wait about 30 s for the Pi to boot (`main.py` is then in WAITING), then press START.

Live log: `journalctl -u dashboard.service -u master.service -f`. Stop it for bench work: `sudo systemctl stop master.service`.

For a scored round, put the SD card in a laptop and create an empty file named `COMPETITION` on the boot partition. Delete it again to get Wi-Fi and SSH back.

Install on a fresh Pi:

```bash
sudo cp dashboard.service master.service wro-radio.service /etc/systemd/system/
sudo cp wro-radio.sh /usr/local/bin/ && sudo chmod +x /usr/local/bin/wro-radio.sh
sudo systemctl daemon-reload && sudo systemctl enable wro-radio.service dashboard.service master.service
```

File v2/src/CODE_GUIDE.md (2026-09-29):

# How our code works: a guide for editing it yourselves

This guide is for making changes to the V2 code **without help**. It walks
through the important lines of each program: what they do, why they are
written that way, and what the syntax means. It covers three things:

1. **[Parking](#part-1-parking-on-its-own)**: the parking exit system configured in `flasher.py` (`open_slave.ino` on the ESP32 + `parking_master.py` on the Pi)
2. **[Obstacle round](#part-2-the-obstacle-round-on-its-own)**: the Pi + ESP32 system that drives laps and dodges pillars
3. **[Both combined](#part-3-parking--obstacle-round-combined)**: how `main.py` integrates the parking exit and obstacle round together into one unified run
4. **[Every parameter](#part-4-every-parameter-explained)**: what each slider and constant does, and which ones to change to get the behaviour you want

Read [Part 0](#part-0-things-you-need-before-anything-else) first. It covers
the syntax used everywhere else, and the sections after it assume you know it.

Line numbers such as `main.py:457` are correct as of commit `5a1de4d`. If they
have moved a little, search for the function name instead.

For **running** the car on competition day (services, flashing, SSH), use
[`RUNBOOK.md`](RUNBOOK.md). This guide explains the code, not the operating steps.

---

## Contents

- [Part 0: things you need before anything else](#part-0-things-you-need-before-anything-else)
  - [0.1 The hardware in one picture](#01-the-hardware-in-one-picture)
  - [0.2 Units and sign conventions](#02-units-and-sign-conventions-memorise-these)
  - [0.3 Arduino / C++ syntax you will meet](#03-arduino--c-syntax-you-will-meet)
  - [0.4 Python syntax you will meet](#04-python-syntax-you-will-meet)
  - [0.5 The one idea everything is built on: blocking vs tick-based](#05-the-one-idea-everything-is-built-on-blocking-vs-tick-based)
- [Part 1: parking on its own](#part-1-parking-on-its-own)
  - [1.1 Architecture in flasher.py](#11-architecture-in-flasherpy)
  - [1.2 ESP32 slave firmware: open_slave.ino](#12-esp32-slave-firmware-open_slaveino)
  - [1.3 Pi controller: parking_master.py](#13-pi-controller-parking_masterpy)
  - [1.4 Tunable parameters: parking/config.py](#14-tunable-parameters-parkingconfigpy)
  - [1.5 How to run and test parking](#15-how-to-run-and-test-parking)
  - [1.6 Historical standalone sketches](#16-historical-standalone-sketches)
- [Part 2: the obstacle round on its own](#part-2-the-obstacle-round-on-its-own)
- [Part 3: parking + obstacle round combined](#part-3-parking--obstacle-round-combined)
- [**Part 4: every parameter, explained (and which to change for what)**](#part-4-every-parameter-explained)
- [Part 5: how to change things safely (recipes)](#part-5-how-to-change-things-safely-recipes)
- [Part 6: when it misbehaves, where to look](#part-6-when-it-misbehaves-where-to-look)

---

# Part 0: things you need before anything else

## 0.1 The hardware in one picture

```
                 USB cable, 115200 baud, one text line per message
 ┌──────────────────────┐  ──── "90,87\n"  (speed,steering) ───▶ ┌─────────────────────────┐
 │  Raspberry Pi 5      │                                          │  ESP32-C3 Super Mini    │
 │  - camera + YOLO     │ ◀─── "DATA,52,40,61,999,93.4,...,1234\n" │  - 4 ToF via mux        │
 │  - all decisions     │                                          │  - BNO055 IMU (mux ch4) │
 │  - dashboard :8080   │ ◀─── "START\n" / "STOP\n"                │  - motor, servo, encoder│
 └──────────────────────┘                                          │  - START button GPIO10  │
                                                                   └─────────────────────────┘
```

| Thing | Pin / channel | Notes |
|---|---|---|
| Motor PWM (speed) | GPIO **1** | `analogWrite(1, 0..255)` |
| Motor DIR | GPIO **0** | `LOW` = forward, `HIGH` = reverse |
| Steering servo | GPIO 6 | degrees; physical stops 28..142, we use **30..140** |
| NeoPixel LEDs | GPIO 7 | 16 LEDs |
| I²C | SDA 8, SCL 9 | everything goes through the TCA9548A mux at `0x70` |
| ToF front / left / right / rear | mux ch **0 / 1 / 2 / 3** | left and right were swapped on the car, so ch1 = LEFT |
| BNO055 IMU | mux ch **4** | select ch4 before reading it |
| Wheel encoder | A = GPIO4 (interrupt), B = GPIO5 | **2078 ticks = 1 metre** |
| START button | GPIO10 to GND | reads `LOW` when pressed (internal pull-up) |

## 0.2 Units and sign conventions (memorise these)

These cause more bugs than anything else in this code.

| Quantity | Convention |
|---|---|
| **Servo angle** | Degrees. **90 is not straight on this car. 87 is.** The Pi writes that as `SERVO_CENTER (90) + servo_trim_deg (-3)`. **Bigger number = wheels RIGHT.** |
| **Yaw / heading** | BNO055, 0..359.9°, **clockwise = increasing**. Turning right makes yaw go up. |
| **Heading error** | `heading_error(target, current)` gives -180..+180. **Positive = you need to turn RIGHT.** |
| **Speed** | PWM, -110..+110 (`MAX_PWM = 110`). Negative = reverse. Below ~80 the motor may not move at all. |
| **Distance** | cm everywhere. From the encoder: `cm = abs(ticks_now - ticks_at_start) / 20.78`. |
| **ToF** | cm. **999 means "nothing in range"**, i.e. an open side or a gap. |
| **Lap direction** (`self.lock`) | `+1` = clockwise (CW) = every corner is a **right** turn. `-1` = anticlockwise (CCW) = **left** turns. `0` = not decided yet. |
| **Pillar colour** | **Red is passed on the RIGHT** (the car goes right). **Green is passed on the LEFT.** |
| **Reversing** | Reversing **flips the steering effect**. The same servo angle rotates the car the other way when the wheels go backwards, so every "hold heading while reversing" formula has a **minus** where the forward one has a plus. |

## 0.3 Arduino / C++ syntax you will meet

```cpp
#define SPEED 90          // A text substitution done before compiling. Everywhere the
                          // word SPEED appears, the compiler sees 90. No '=' and no ';'.

volatile long ticks = 0;  // 'volatile' = "this can change behind your back" (an interrupt
                          // changes it), so the compiler must re-read it every time.

void IRAM_ATTR encISR() { ... }   // An Interrupt Service Routine. The hardware calls it by
                                  // itself on every encoder pulse. IRAM_ATTR keeps it in fast RAM.
                                  // Keep ISRs tiny: no Serial, no delay.

attachInterrupt(digitalPinToInterrupt(4), encISR, RISING);
                          // "Call encISR every time pin 4 goes from LOW to HIGH."

noInterrupts(); t = ticks; interrupts();
                          // Pause interrupts while copying a multi-byte value, so the ISR
                          // cannot change it half-way through the copy.

digitalRead(ENC_B) ? ticks++ : ticks--;
                          // Ternary: condition ? do_if_true : do_if_false

constrain(x, 30, 140)     // Clamp x into [30, 140].
fabs(x)                   // Absolute value of a float. abs() is for ints.
millis()                  // Milliseconds since power-on. Used for non-blocking timing.
delay(20)                 // Freeze EVERYTHING for 20 ms. Fine in simple sketches, banned in open_slave.

Serial.printf("L=%.0f R=%.0f\n", L, R);
                          // Formatted print. %d int, %ld long, %.1f float with 1 decimal,
                          // %s string, %u unsigned. \n = newline.

snprintf(buf, sizeof(buf), "DATA,%u,...", a, ...);
                          // Same as printf, but writes into a char array instead of the port.

long v = strtol(p, &end, 10);
                          // Parse a base-10 integer from text. 'end' is left pointing just
                          // after the number, which is how the code finds the ',' next.

bool f(...);  float g(...);  void h(...);
                          // Function return types: true/false, a decimal number, nothing.

const char *label         // A text string passed into a function, e.g. "1 TURN OUT".
Adafruit_VL53L0X tof[3];  // An array of 3 sensor objects: tof[0], tof[1], tof[2].
1 << ch                   // Bit shift: 1<<0=1, 1<<1=2, 1<<4=16. The mux takes a
                          // bitmask where bit N means "open channel N".
```

Every Arduino sketch has two required functions:

- `setup()` runs **once** at power-on or reset.
- `loop()` runs **forever**, over and over, after `setup()` finishes.

## 0.4 Python syntax you will meet

```python
class ObstacleRound:              # A class groups state (variables) and behaviour (functions).
    def __init__(self, start_yaw, now):   # The constructor. Runs once when you do
        self.target = start_yaw           #   ctl = ObstacleRound(yaw, now)
                                          # 'self.x' is a variable that lives as long as the object.

    def _park_step(self, d, now): ...     # A method. A leading '_' just means "internal helper".
                                          # 'self' is always the first parameter.

    @property
    def direction(self): ...              # Called WITHOUT brackets: ctl.direction, not ctl.direction()

d["yaw"]                    # Dictionary lookup. Crashes if the key is missing.
d.get("ticks")              # Same, but returns None if missing.
p.get("park_turn_deg", 90)  # ...or returns the default 90 if missing.

x = a if cond else b        # Python's ternary: the same as C's  cond ? a : b

max(lo, min(hi, v))         # Clamp v into [lo, hi]. You will see this constantly.

f"turned {turned:.1f} deg"  # f-string: {expression:format}. :.1f = 1 decimal, :+.0f = sign + 0 dp.

try:
    v = float(p.get(key, 30.0))
except (TypeError, ValueError):   # If the slider value is junk (None, "abc"), do not crash
    v = 30.0                      # the car mid-run. Use the fallback.

self.park_step, self.park_ticks0 = 2, self.ticks
                            # Assign two variables at once.

[b for b in blocks if b["class"] in ("Red", "Green")]
                            # List comprehension: "every b in blocks that is Red or Green".

sorted(blocks, key=lambda b: b["dist_cm"])
                            # Sort by distance. 'lambda b: ...' is a tiny unnamed function.

min(blocks, key=lambda x: x["dist_cm"])      # The nearest block.

(a + 90.0) % 360.0          # Modulo: wraps 400 -> 40. Keeps headings inside 0..359.

log.info(...)  log.warning(...)  log.error(...)
                            # Written to the journal (journalctl -u master.service).
                            # This is how you see what the car decided.
```

## 0.5 The one idea everything is built on: blocking vs tick-based

There are two ways to write "turn until 90°, then drive 30 cm":

**Blocking** (early experimental sketches like `parking_exit_v2.ino`): the function sits in a `while`
loop until it is finished. It is easy to read, but nothing else can run in the
meantime.

```cpp
while (turned < 90) { steer hard; drive; delay(20); }   // stuck here until done
while (cm < 30)     { hold heading; drive; delay(20); }
```

**Tick-based** (both `parking_master.py` and `main.py`): a function is called
about **50 times a second** by the control loop. Each call looks at the telemetry once,
decides once, returns one `(speed, steer)` pair, and exits immediately. It remembers
where it was in state variables such as `self.stage` in `parking_master.py` or
`self.park_step` and `self.pillar_stage` in `main.py`. This is called a **state machine**.

```python
def step(self, d, now):            # called every ~20 ms
    if self.stage == "TURN_OUT":   # "which stage am I in?"
        if self._stage_done(target_cm, now):
            self._begin_stage("STRAIGHT", now)
        else:
            return speed, steer    # one command, then return
```

By using the tick-based state machine, `parking_master.py` shares the exact same
modular architecture as the obstacle round. This is what makes it straightforward to
integrate parking directly into `main.py` (Part 3) so one START press does both
without any firmware changes.

---

# Part 1: parking on its own

In our codebase, parking is configured as an independent operational mode in
[`obstacle_round/pi/flasher.py`](obstacle_round/pi/flasher.py):

```python
    "parking": {
        "label": "Parking test",
        "sketch": "open_slave",
        "build": "build_slave",
        "service": "parking.service",
        "blurb": "test only - the parking exit on its own",
    },
```

Unlike early monolithic sketches, the parking exit system uses our standard
two-tier architecture:
1. **ESP32 Firmware:** [`obstacle_round/esp/open_slave/open_slave.ino`](obstacle_round/esp/open_slave/open_slave.ino) (pure hardware slave: streams sensor telemetry, controls motor and servo, enforces safety watchdog).
2. **Raspberry Pi Controller:** [`parking/parking_master.py`](parking/parking_master.py) with [`parking/config.py`](parking/config.py), managed by `parking.service`.

> **Note on code integration:** While `parking_master.py` runs parking as a standalone
> test, the repository also contains the unified code that **integrates both parking
> and the obstacle round together**: [`obstacle_round/pi/main.py`](obstacle_round/pi/main.py)
> (covered in detail in [Part 3](#part-3-parking--obstacle-round-combined)).

### What it does

When the START button is pressed on the car or web dashboard:
```
1. LOOK: Compare Left vs Right ToF
   - Wall on LEFT  (Left <= Right) → Exit to the RIGHT (exit_dir = +1)
   - Wall on RIGHT (Right < Left)  → Exit to the LEFT  (exit_dir = -1)

2. STAGE 1: TURN OUT (25 cm via encoders)
   - Steer lock away from wall (SERVO_CENTER + exit_dir * 50°)
   - Hold lock for first 40% of distance, then progressively unwind towards center

3. STAGE 2: STRAIGHT ACROSS LANE (55 cm via encoders)
   - Hold perpendicular heading (~80° off start) via IMU P-controller (HOLD_KP = 1.5)

4. STAGE 3: TURN BACK / RECENTER (25 cm via encoders)
   - Opposite lock (SERVO_CENTER - exit_dir * 50°) to swing parallel to lane

5. STAGE 4: FORWARD TO SQUARE UP (20 cm via encoders)
   - Drive forward holding original 0° heading to square up with the track

6. HALT:
   - Motor cut (0 PWM), steering centered (87°). Complete standstill.
```

---

## 1.1 Architecture in flasher.py

The mode switching logic in `flasher.py` automates the entire parking workflow:
1. **Stops any conflicting service:** Halts `master.service` so two processes never fight over the vehicle.
2. **Compiles the firmware:** Invokes `arduino-cli` on `open_slave.ino` targeting the ESP32-C3 (`build_slave` directory).
3. **Flashes over serial:** Pauses the serial interface, flashes the merged binary to the ESP32 via `esptool`, and resumes the port.
4. **Activates the service:** Sets `parking.service` as the active systemd service, starting `parking_master.py` immediately and enabling it on boot.

Because both parking and obstacle rounds run on `open_slave.ino`, **you do not need a custom Arduino sketch on the ESP32 to run parking**. The microcontroller always runs the standard slave firmware, while the Pi determines the driving behavior.

---

## 1.2 ESP32 slave firmware: `open_slave.ino`

`open_slave.ino` runs on the ESP32-C3 Super Mini and has **zero autonomous driving logic**. It serves as a reliable, high-speed hardware interface:

- **Telemetry streaming (50 Hz):**
  Reads the TCA9548A I2C mux (channels 0..3: ToF front, left, right, rear; channel 4: BNO055 IMU) and wheel optical encoder, streaming text frames over USB serial (115200 baud):
  ```
  DATA,front,left,right,rear,yaw,sys,gyro,accel,mag,spd,str,ticks\n
  ```
- **Command execution:**
  Parses incoming drive lines from the Pi:
  ```
  <speed>,<steering>\n    (e.g., "75,137\n" or "0,87\n")
  ```
  Applies soft motor acceleration ramp and sets servo steering angle within calibrated limits (`[30, 140]`).
- **500 ms Safety Watchdog:**
  If the Pi stops sending commands for 500 ms (`WATCHDOG_MS`), the ESP32 immediately cuts motor throttle to 0 and displays a red status LED.

---

## 1.3 Pi controller: `parking_master.py`

`parking_master.py` is the state-machine controller that drives the car during a parking test.

### 1. Connection and telemetry
It connects to the ESP32 either through the dashboard UDP relay (`HubLink` on port 5005) or via direct serial fallback (`/dev/serial/by-id/usb-Espressif*`):
```python
link, is_hub = connect_link()
```

### 2. Idle state and START / STOP control
In the idle state (`ctl is None`), it prints live telemetry once every second:
```python
print(f"IDLE | Hdg={d['yaw']:5.1f}° | F={d['front']:3.0f} cm | "
      f"L={d['left']:3.0f} cm | R={d['right']:3.0f} cm | Ticks={d.get('ticks', 0)}")
```
When START is triggered:
- An instance of `ParkingController` is instantiated with the initial sensor readings.
- If the START/STOP button is pressed mid-run, `parking_master.py` immediately commands `(0, SERVO_CENTER)` to halt the car.

### 3. Exit direction decision
The car measures the side walls with ToF sensors:
```python
self.exit_dir = 1 if left_cm <= right_cm else -1
self.wall_side = "LEFT" if self.exit_dir == 1 else "RIGHT"
self.exit_side = "RIGHT" if self.exit_dir == 1 else "LEFT"
```
- Closer to the **LEFT** wall $\rightarrow$ exit **RIGHT** (`exit_dir = +1`).
- Closer to the **RIGHT** wall $\rightarrow$ exit **LEFT** (`exit_dir = -1`).

### 4. The 4 stages of `ParkingController.step(d, now)`

The state machine runs on every telemetry tick (~50 Hz):

```python
# Stage distance calculated from encoder ticks:
self.stage_cm = abs(self.ticks - self.stage_ticks0) / config.TICKS_PER_CM
```

#### Stage 1: `TURN_OUT` (25 cm)
```python
sharp_steer = config.SERVO_CENTER + self.exit_dir * config.STEER_LOCK_DEG
progress = min(1.0, max(0.0, self.stage_cm / max(1.0, config.TURN_OUT_CM)))
if progress <= 0.40:
    steer = sharp_steer
else:
    unwind = (progress - 0.40) / 0.60
    steer = sharp_steer + (config.SERVO_CENTER - sharp_steer) * (unwind ** 1.5)
```
- Wheels turn to full lock away from the wall (`87 + 50 = 137°` right, or `87 - 50 = 37°` left).
- Full lock is held for the first 40% of the 25 cm travel. Over the remaining 60%, steering unwinds smoothly toward center.
- Transitions to `STRAIGHT` when `self.stage_cm >= config.TURN_OUT_CM` (25 cm).

#### Stage 2: `STRAIGHT` across lane (55 cm)
```python
leg_target_hdg = wrap180(self.start_yaw + self.exit_dir * 80.0)
herr = heading_error(leg_target_hdg, yaw)
steer = config.SERVO_CENTER + clamp(config.HOLD_KP * herr, -25.0, 25.0)
```
- Drives forward across the lane at speed 75 PWM.
- BNO055 heading-hold P-controller maintains heading offset ~80° relative to start wall (`HOLD_KP = 1.5`).
- Transitions to `RECENTER` when `self.stage_cm >= config.STRAIGHT_CM` (55 cm).

#### Stage 3: `RECENTER` (25 cm)
```python
sharp_return = config.SERVO_CENTER - self.exit_dir * config.STEER_LOCK_DEG
progress = min(1.0, max(0.0, self.stage_cm / max(1.0, config.TURN_IN_CM)))
if progress <= 0.40:
    steer = sharp_return
else:
    unwind = (progress - 0.40) / 0.60
    steer = sharp_return + (config.SERVO_CENTER - sharp_return) * (unwind ** 1.5)
```
- Wheels counter-steer sharply in the opposite direction (`SERVO_CENTER - exit_dir * 50°`) to swing the chassis parallel with the lane.
- Holds lock for 40% of travel, unwinding over the last 60%.
- Transitions to `FORWARD_20CM` when `self.stage_cm >= config.TURN_IN_CM` (25 cm).

#### Stage 4: `FORWARD_20CM` & Align (20 cm)
```python
herr = heading_error(self.start_yaw, yaw)
steer = config.SERVO_CENTER + clamp(config.HOLD_KP * herr, -25.0, 25.0)
```
- Squares up with the track by holding the initial heading (`self.start_yaw`).
- Runs forward strictly 20.0 cm measured by the wheel encoder.
- Upon completion, returns `(0, config.SERVO_CENTER, True)`. Motor is cut (`0 PWM`), wheels centered (`87°`), and car halts.

---

## 1.4 Tunable parameters: `parking/config.py`

Constants for the standalone parking exit are configured in [`parking/config.py`](parking/config.py):

| Parameter | Value | Meaning |
|---|---|---|
| `EXIT_SPEED` | 75 | Motor PWM during parking exit |
| `SERVO_CENTER` | 87 | Calibrated straight wheel angle (-3° trim) |
| `SERVO_MIN` / `SERVO_MAX` | 30 / 140 | Software steering travel limits |
| `STEER_LOCK_DEG` | 50 | Angle offset for turning arcs (137° right / 37° left) |
| `TURN_OUT_CM` | 25.0 | Distance for Stage 1 turn-out arc |
| `STRAIGHT_CM` | 55.0 | Distance for Stage 2 cross-lane drive |
| `TURN_IN_CM` | 25.0 | Distance for Stage 3 turn-back arc |
| `FORWARD_CM` | 20.0 | Distance for Stage 4 squaring-up drive |
| `HOLD_KP` | 1.5 | Gain for heading-hold P-controller |
| `TICKS_PER_CM` | 20.78 | Wheel encoder calibration factor (2078 ticks/m) |
| `STAGE_TIMEOUT_S` | 14.0 | Failsafe timeout per stage in case encoder stalls |

---

## 1.5 How to run and test parking

### A. From the web dashboard
1. Connect to dashboard at `http://error404.local:8080`.
2. Under the Round switcher, select **Parking test**.
3. `flasher.py` compiles and flashes `open_slave.ino` (if needed) and activates `parking.service`.
4. Press START on the car or web dashboard.

### B. From the command line
Switch modes using `flasher.py`:
```bash
python3 /home/pi/obstacle_round/flasher.py parking
```

Or run interactively in the terminal:
```bash
# Stop competing services so they don't fight over the serial port
sudo systemctl stop master.service parking.service

# Run parking master script
python3 /home/pi/parking/parking_master.py
```

### C. Viewing live logs
To monitor state transitions and sensor data:
```bash
journalctl -u parking.service -f
```

---

## 1.6 Historical standalone sketches

For reference, the repository also contains earlier standalone parking experiments:
- `parking_exit/esp/parking_exit_v2/parking_exit_v2.ino`: An earlier standalone C++ sketch running
  entirely on the ESP32 using blocking `while` loops.
- `parking/esp/parking_exit_standalone/`: A 5-stage distance-based ESP32 standalone sketch.

While useful as early hardware prototypes, they required repeatedly reflashing the ESP32 between
standalone sketches and `open_slave`. The current architecture in `flasher.py` unifies everything
around `open_slave.ino` on the ESP32 and `parking_master.py` on the Pi.

---

# Part 2: the obstacle round on its own

## 2.1 Who does what

```
 ESP32: open_slave.ino
   reads sensors, streams DATA at 50 Hz, applies speed/steer, watchdog
          │ USB serial
          ▼
 Pi: dashboard.py  (dashboard.service, ALWAYS running from boot)
   - the ONLY program that opens the serial port and the camera
   - runs YOLO on each camera frame (vision.py)
   - serves the web page on :8080 with the live sliders (params.json)
   - relays everything to main.py over UDP on localhost:5005
          │ UDP  (HubLink in serial_link.py)
          ▼
 Pi: main.py  (master.service)
   - ObstacleRound.step(data, blocks, params, now) → (speed, steer)
   - ~50 times a second
```

| File | Job |
|---|---|
| `obstacle_round/esp/open_slave/open_slave.ino` | ESP32 firmware. **No driving logic at all.** |
| `obstacle_round/pi/main.py` | **All the driving decisions.** This is the file you edit most. |
| `obstacle_round/pi/config.py` | Fixed constants, plus `DEFAULT_PARAMS` (the defaults for every slider). |
| `obstacle_round/pi/params.json` | The **live tuned values**, written by the dashboard sliders. |
| `obstacle_round/pi/serial_link.py` | Message formats and the UDP link (`HubLink`). |
| `obstacle_round/pi/vision.py` | YOLO pillar detection. Turns a frame into a list of blocks with distances. |
| `obstacle_round/pi/pixel_distance_method.py` | Sizes the dodge from how far off-centre the pillar is. |
| `obstacle_round/pi/dashboard.py` | Web page, camera, relay. |
| `obstacle_round/pi/tools/*.py` | Tests that need no hardware. |

---

## 2.2 The ESP32 slave: `open_slave.ino`

### The message format

```
Pi → ESP32:   "<speed>,<steering>\n"         e.g. "90,87\n"   "-90,120\n"   "0,90\n"
              "STOP\n" / "START\n"

ESP32 → Pi:   "DATA,F,L,R,B,yaw,sys,gyro,accel,mag,spd,str,ticks\n"   every 20 ms
               field 0 1 2 3  4   5    6    7     8   9   10  11   12
              "START\n"   (button pressed; repeated every 1 s until the Pi answers)
              "STOP\n"    (button pressed during a run)
              "INFO,..." / "ERR,..."
```

### The important parts

**The encoder ISR** is the same idea as the parking sketch:
```cpp
void IRAM_ATTR encISR() { if (digitalRead(ENC_B_PIN)) encTicks++; else encTicks--; }
```

**The motor** has a soft start that ramps 30 PWM every 8 ms, so the wheels do not spin:
```cpp
if (appliedSpeed < target) appliedSpeed = min(appliedSpeed + RAMP_STEP, target);
```

**Parsing a command** (`handleLine`):
```cpp
long speed = strtol(line, &end, 10);         // "90,87" → 90, end points at ','
if (end == line || *end != ',') return;      // not a number, or no comma → ignore
long steer = strtol(end + 1, &end, 10);      // → 87
lastCmdMs = now;                             // feeds the watchdog
if (!started) return;                        // rule: no driving before START
targetSpeed = constrain(speed, -MAX_PWM, MAX_PWM);
steerCmd   = constrain(steer, SERVO_MIN, SERVO_MAX);
```
The ESP32 **clamps again**, independently of the Pi. This is why raising
`MAX_PWM` on the Pi alone does nothing: **it must be raised in both places.**

**The watchdog**, in `loop()`:
```cpp
watchdogTripped = started && (now - lastCmdMs > WATCHDOG_MS);   // 500 ms
updateMotor(now, (started && !watchdogTripped) ? targetSpeed : 0);
```
If the Pi crashes or goes quiet for half a second, the car stops by itself.

**`loop()` never uses `delay()`.** Every job runs on its own `millis()` timer:
```cpp
if (now - lastSensorMs >= SENSOR_PERIOD_MS) { lastSensorMs = now; ...read sensors... }
if (now - lastTelemetryMs >= TELEMETRY_PERIOD_MS) { lastTelemetryMs = now; sendTelemetry(); }
```
This is the standard Arduino pattern for "do X every N ms without blocking".

**The LED** shows the state: blue = waiting for START, green = running, red = watchdog tripped, orange = a sensor is missing.

> ⚠️ Any change to this file means you must **reflash the ESP32**.

---

## 2.3 The link: `serial_link.py`

```python
def parse_data(line):
    p = line.split(",")                       # "DATA,52,40,..." → ["DATA","52","40",...]
    if len(p) not in (12, 13): return None
    return {"front": int(p[1]), "left": int(p[2]), "right": int(p[3]), "rear": int(p[4]),
            "yaw": float(p[5]), ..., "ticks": int(p[12]) if len(p) == 13 else None, ...}
```
This turns one DATA line into the dictionary `d` that the whole of `main.py`
reads: `d["front"]`, `d["yaw"]`, `d["ticks"]`, and so on.

```python
def command_line(speed, steering):
    speed = int(max(-config.MAX_PWM, min(config.MAX_PWM, round(speed))))
    steering = int(max(config.SERVO_MIN, min(config.SERVO_MAX, round(steering))))
    return f"{speed},{steering}\n"
```
Every command passes through here, **so the Pi can never send an unsafe value.**

**`HubLink`** is what `main.py` uses. The methods you will see:

| Call | Returns / does |
|---|---|
| `link.wait_new(seq, timeout)` | Waits for the next DATA line. Returns `(d, seq)`. `d["age"]` = seconds since it arrived. |
| `link.latest_vision()` | List of pillar blocks from the newest camera frame (`[]` if older than 0.5 s). |
| `link.vision_seq` | Counter that goes up once per **camera frame**. Used to count frames, not ticks. |
| `link.latest_params()` | Dict of all slider values. |
| `link.start_received` | `True` after START is pressed, `False` after STOP. |
| `link.send(speed, steer)` | Sends a drive command. |
| `link.publish({...})` | Sends status to the dashboard page. |

---

## 2.4 Vision: `vision.py`

Every detected pillar ("block") is a dict:
```python
{'class': 'Red', 'confidence': 0.93, 'x1':..,'y1':..,'x2':..,'y2':.., 'cx': 335, 'cy':..,
 'w':.., 'h':.., 'area':.., 'dist_cm': 48.2, 'clipped': False}
```

The distance comes from the pinhole camera formula:
```python
return focal_px * config.PILLAR_HEIGHT_CM / max(1, h_px)     # 443.8 * 10 / box height
```
A pillar is 10 cm tall, so a box that is twice as tall means the pillar is
half as far away. When the box is **cut off at the top or bottom of the frame**
(`clipped`), the height is wrong, so the 5 cm **width** is used instead.

Regions of interest ("ROI" bands) are in `config.py`:
```python
def block_roi(block, frame_w=None):  # → "LEFT" / "CENTER" / "RIGHT"
```
The frame is split into three vertical bands, and a block belongs to whichever
band holds **most of its box**. The dashboard draws the bands with the same
function, so what you see matches what the car decides.

---

## 2.5 Settings: `config.py`, `params.json` and the sliders

There are **three layers**. This is the most common source of "I changed it
and nothing happened".

| Layer | Where | Changed how | Needs restart? |
|---|---|---|---|
| **Hard constants** | `config.py`, `UPPER_CASE = value` | Edit the file, deploy | Yes (restart `master.service`) |
| **Slider defaults** | `config.py`, `DEFAULT_PARAMS = {...}` | Edit the file, deploy | Yes |
| **Live values** | `params.json` on the Pi | Dashboard sliders at `http://error404.local:8080` | **No, applies instantly** |

How they combine (`config.load_params`):
```python
def load_params():
    params = dict(DEFAULT_PARAMS)              # 1. start from the defaults
    if os.path.exists(PARAMS_FILE):
        data = json.load(f)
        for k, v in data.items():
            if k in params:                     # 2. only keys that EXIST in DEFAULT_PARAMS
                params[k] = type(params[k])(v)  #    converted to the default's type (int/float/bool)
    return mirror_green(params)                 # 3. green settings overwritten from red
```

Three things follow from this:
- **A new key added only to `params.json` is ignored.** It must also be in `DEFAULT_PARAMS`.
- **Green settings are ignored.** `mirror_green` copies every red value onto its green counterpart. **To tune the dodge, tune the RED sliders.** Green follows automatically as an exact mirror.
- `deploy.sh` **never overwrites** the Pi's `params.json`. It copies the Pi's copy back to your laptop first, so the tuning done at the track survives a deploy.

How `main.py` reads a slider (the pattern is everywhere):
```python
try:
    v = float((self._params or {}).get("pre_turn_reverse_cm", 30.0))
except (TypeError, ValueError):
    return 30.0
return max(0.0, min(150.0, v))     # clamp, so a typo cannot send the car 3 m
```
`self._params or {}` means "the params dict, or an empty dict if it is None".

### The sliders you will actually touch (the full list is in [Part 4](#part-4-every-parameter-explained))

| Key | Current | Meaning |
|---|---|---|
| `base_speed` / `turn_speed` / `reverse_speed` | 90 | PWM (capped at 110) |
| `front_turn_cm` | 37 | Front distance at which a corner is taken |
| `corner_steer_deg` | 28 | Maximum degrees off straight during a corner turn |
| `pre_turn_reverse_cm` | 35 | Reverse-arc before each corner, for room |
| `reverse_arc_deg` / `reverse_arc_leave_deg` | 40 / 35 | Wheel angle in the reverse arc / degrees left for the forward part |
| `post_turn_reverse_cm` | 40 | Straight reverse after each corner |
| `cruise_wall_k` / `cruise_target_cm` | 1.6 / 42 | Wall-centring strength / distance to hold off the outer wall |
| `pillar_trigger_dist_cm` | 30 | Camera distance at which the dodge starts |
| `pillar_steer_right` | 135 | Red turn-out angle (Green is mirrored from it) |
| `dodge_short_cm` / `dodge_long_cm` | 29 / 35 | Turn-out leg lengths (normal / wide). **Unused while `use_pixel_dodge` is on.** |
| `dodge_past_cm` | 50 | Straight run past the pillar |
| `dodge_red_extra_cm`, `dodge_past_red_extra_cm`, ... | | Per-colour trims (red only, see above) |
| `use_pixel_dodge` | true | Size the turn-out from the pillar's pixel offset instead |
| `recenter_k` / `recenter_target_cm` | 2.0 / 45 | Wall centring during ALIGN after a dodge |
| `servo_trim_deg` | -3 | 90 + this = true straight |
| `park_*` | | Parking exit, see Part 3 |

---

## 2.6 `main.py` part A: the main loop (`main()`, line ~2005)

This is the outer program. Simplified, it looks like this:

```python
link = HubLink()                                   # connect to dashboard.py
ctl = None                                         # no run in progress

while not stop["flag"]:
    d, seq = link.wait_new(seq, timeout=0.1)       # 1. newest sensor data
    now = time.monotonic()                         #    a clock that never jumps backwards
    fresh = d is not None and d["age"] <= config.TELEMETRY_MAX_AGE_S

    if ctl is not None and not link.start_received:    # 2. STOP pressed during a run
        ctl = None; link.send(0, config.SERVO_CENTER)

    if ctl is None and link.start_received and fresh:  # 3. START pressed → new run
        link.clear_vision()
        ctl = ObstacleRound(d["yaw"], now)              #    the current heading = "straight"
        ctl.lock_direction_from_parking(d)              #    CW or CCW, decided ONCE
        ctl._params = link.latest_params() or {}
        ctl.begin_parking(d, now)                       #    arm the parking exit (Part 3)
        ...open a CSV log file...

    if ctl is None:            speed, steer = 0, config.SERVO_CENTER
    elif not fresh:            speed, steer = 0, ...; link.send(...)   # 4. stale data → stop
    else:
        blocks = link.latest_vision()
        params = link.latest_params()
        speed, steer = ctl.step(d, blocks, params, now)   # 5. THE DECISION
        link.send(speed, steer)                           # 6. to the ESP32
        writer.writerow([...])                            # 7. one CSV row per tick
```

- **`ObstacleRound` is created fresh on every START**, so every run starts clean.
- Every run writes `obstacle_round/logs/run_YYYYMMDD_HHMMSS.csv`, with one row per tick: sensors, target heading, stage, speed and steer. **This is the first thing to read after a bad run.**
- The part that checks for missing `ticks` near the top of the loop only matters if the ESP32 is running the stand-alone open-round sketch. In that case `main.py` just watches and sends nothing.

---

## 2.7 `main.py` part B: `step()`, the brain (line ~1182)

`step()` is called every tick and **returns as soon as one part claims the
car**. The **order of the `if` blocks is the priority order**:

```
step(d, blocks, params, now):
  0. housekeeping: de-glitch ToF, heading error, note close pillars, read encoder
  1. state == DONE                 → stop
  2. park_step != 0                → parking exit owns the car             (Part 3)
  3. state == FINISHING            → drive 3 s past turn 12, then DONE
  4. is_turning                    → corner turn in progress
  5. pre_turn_reverse              → reverse-arc before a corner
  6. post_turn_reverse             → straight reverse after a corner
  7. should turn? (not mid-dodge)  → start a corner
  8. no pillar tracked?            → look for one in `blocks`
  9. pillar_stage == BACKOFF       → reverse away from a too-close pillar
 10. pillar_stage == APPROACH      → cruise, wait for the trigger distance
 11. pillar_stage == TURN_OUT      → dodge leg 1
 12.                 STRAIGHTEN    → dodge leg 2
 13.                 RECENTER      → dodge leg 3 (turn back in)
 14.                 ALIGN         → dodge leg 4 (square up)
 15. otherwise                     → normal cruising with wall centring
```

The rules that fall out of this order:
- A **dodge, once started, is never interrupted** (`dodge_running` blocks corners in step 7).
- A **corner outranks a dodge that has not started yet** (APPROACH is dropped if a corner comes).
- Each block ends with `self.last_t = now; return speed, steer`. The `return` is what gives it ownership of the car for this tick.

### Housekeeping at the top of `step()`

```python
self._params = params or {}
d = self._deglitch_tof(d, now)                   # see 2.8
self.herr = heading_error(self.target, d["yaw"]) # + = must turn right
...
t = d.get("ticks")
if t is None: self.ticks_ok = False
else:
    self.ticks_ok = True
    self.ticks = t
    self.stage_cm = abs(self.ticks - self.stage_ticks0) / config.TICKS_PER_CM
```
`self.stage_cm` is **"cm driven since the current stage began"**. Every
distance-based stage ends when it reaches its target. `_begin_stage()` resets
it to 0:

```python
def _begin_stage(self, stage, now):
    self.pillar_stage = stage
    self.stage_t0 = now
    self.stage_ticks0 = self.ticks       # ← new reference point
    self.stage_cm = 0.0

def _stage_done(self, target_cm, now):
    if self.ticks_ok and self.stage_cm >= target_cm: return True
    return (now - self.stage_t0) >= config.STAGE_TIMEOUT_S   # 6 s backstop for a dead encoder
```

---

## 2.8 `main.py` part C: driving straight

### `heading_error()` (line 38)
```python
def heading_error(target, current):
    d = target - current
    while d > 180:  d -= 360
    while d < -180: d += 360
    return d
```
This is the shortest signed angle from `current` to `target`. With target 10
and current 350, it gives +20 (turn right 20°), not -340.

### `_straight()` (line 255): the cruise controller
```python
self.nudge = open_round_wall_centering(d["left"], d["right"], self.lock, kp=k_center, target=target_dist)
steer = self._straight_servo() + config.KP_HEADING_CRUISE * self.herr + self.nudge
return self.base_speed(), clamp_servo(steer)
```
This is the whole straight-line controller:
**servo = true straight (87) + 1.2 × heading error + wall correction**.

`open_round_wall_centering()` (line 82) gives the wall correction in **servo
degrees**:
- **Both walls are seen**: `(right - left) * kp * 0.5`. If the car is nearer the left wall, right > left, the result is positive, and the car steers right.
- **One wall is seen**: hold `target` (42 cm) off it. It prefers the **outer** wall, which depends on the lap direction (`lock`).
- **No wall**: 0, so the car holds heading only.

Set `cruise_wall_k` to 0 for pure-gyro straights.

### `_deglitch_tof()` (line 302)
The ESP32 sends **999 both for "no wall" and for "sensor glitched"**. A single
fake 999 on a side can look like an open corner, and on corner 1 that can set
the **wrong lap direction for the whole race**. So:
- **Low readings** (a real wall) pass straight through.
- A **999** only passes if most readings in the last 0.25 s were also 999. Otherwise it is replaced with the median of the recent real readings.

---

## 2.9 `main.py` part D: corners

### Lap direction: `lock_direction_from_parking()` (line 390)
```python
left, right, ambiguous = self._lock_sides(d)
if ambiguous: self.lock = self._default_lock()           # both open → params "default_lap_dir"
else:         self.lock = 1 if left < right else -1       # nearer LEFT wall → CW → right turns
```
This is decided **once, standing still, at START**, from where the car is
parked. It is the same wall reading that sets the parking exit direction, so
the two can never disagree. The long `_should_turn` code for "lock == 0" only
runs if `LOCK_DIRECTION_AT_START = False` in `config.py`.

### When to turn: `_should_turn()` (line 565)
In order, these checks can say **no**:
1. **A pillar is dead ahead** (seen CLOSE, in the CENTER band, within `block_no_corner_s` seconds): the front ToF is looking at the pillar, not a wall, so this is not a corner.
2. **The car has not driven `MIN_TRAVEL_BETWEEN_TURNS_CM` (20 cm) since the last corner**: this stops it re-triggering on the wall it just turned away from. The exception is when front ≤ 25 cm (critical).
3. **`front <= front_turn_cm` → TURN.** With the direction already locked, that is all it needs.

### The corner sequence
```
_should_turn → True
   │
   ├─ pre_turn_reverse_cm > 0:  corner_target = target + 90*lock
   │     REVERSE ARC: reverse with the wheels turned the OPPOSITE way
   │     (_reverse_arc_steer). The nose swings towards the new heading while
   │     backing off the wall. Stops when only reverse_arc_leave_deg of the
   │     turn is left (or after the set distance or time).
   │
   ├─ _begin_turn():  self.target = corner_target
   │
   ├─ _turn_step() every tick:
   │     steer = _corner_steer(): off = min(cap, max(7, 0.55*|herr|))
   │       → hard while far from the target, easing off as the car comes round
   │     if front < 12 cm: WEDGED → reverse with opposite lock until front > 20
   │     done when |herr| < TURN_DONE_ERR_DEG (13°) or after 6.5 s
   │     turns += 1; if turns >= 12 → FINISHING
   │
   └─ post_turn_reverse_cm > 0:  straight reverse (heading held), then cruise
```

The heading target is **absolute**: `self.target = (self.target + 90.0 * self.lock) % 360.0`.
Each corner adds exactly 90° to the previous target, not to wherever the car
happens to point, so small errors do not add up over 12 corners.

```python
def _reverse_hold_steer(self, herr):
    return clamp_servo(self._straight_servo() - config.KP_REVERSE_HEADING * herr)
#                                            ^ MINUS: reversing flips the steering
```

---

## 2.10 `main.py` part E: pillars

### Picking a pillar (step 8, line ~1386)
Only when **no pillar is being handled** and the car has driven
`pillar_clear_cm` (60 cm) **and** waited `pillar_clear_delay_s` (1.2 s) since
the last dodge. Without that, the camera re-adopts the pillar it has just
passed.

```python
valid = sorted((b for b in blocks if b["class"] in ("Red", "Green")), key=lambda b: b["dist_cm"])
```
**The nearest pillar comes first.** Blocks closer than the floor distance are
dropped, because they are "almost certainly the pillar just passed". Then:
```python
self._begin_stage("APPROACH", now)
```

### APPROACH (step 10)
- Every frame it re-checks: **is a different-coloured pillar now 20 cm nearer?** If so, it switches to that one.
- It updates `pillar_dist` from the nearest block of the tracked colour. A **clipped** box that suddenly reads farther away is ignored, because the pillar cannot be moving away from the car.
- If the pillar is not seen for 1.5 s, it is dropped and the car goes back to cruising.
- **Trigger**: `pillar_dist <= pillar_trigger_dist_cm` for **3 separate camera frames** (`DODGE_TRIGGER_FRAMES`). It counts using `vision_seq`, so three control ticks on the same frame do not count as three.
- **ToF shortcut**: if the pillar is CENTER-band and the front ToF reads ≤ 40 cm **and** agrees with the camera within 25 cm, it commits immediately.
- Until the trigger fires, it just drives with `_straight()`.

When it fires, three decisions are **latched once** (the pillar will leave the
frame as the car turns):
```python
self.pillar_roi = config.block_roi(self.pillar_box ...)          # LEFT / CENTER / RIGHT
self.dodge_wide = (Green and roi == "LEFT") or (Red and roi == "RIGHT")
self.pixel_out_cm = pxd.sideways_cm(...)  if params["use_pixel_dodge"]
self._begin_stage("TURN_OUT", now)
```

### BACKOFF (step 9)
If the pillar is **already inside** the trigger distance when it is picked up
(or stays inside for 0.6 s without committing), the car reverses until the
pillar reads ≥ 35 cm (`BACKOFF_TARGET_CM`), then approaches again. This allows
up to 2 tries. The point is that **every dodge starts from the same distance.**

### The dodge: 4 legs, all measured on the encoder

| Stage | Steering | Ends when |
|---|---|---|
| **TURN_OUT** | Sharp angle for `turn_hold_pct` (30%) of the leg, then unwinds to straight | `stage_cm >= _out_cm()` |
| **STRAIGHTEN** | `_straight(ignore_tof=True)`, gyro only (the inner ToF is looking at the pillar) | `stage_cm >= _past_cm()` |
| **RECENTER** | The mirror angle back in, same hold-then-unwind shape | `stage_cm >= _in_cm()` |
| **ALIGN** | `87 + 2.4*herr` + outer-wall centring | `|herr| < 5°` and a minimum distance, or `ALIGN_MAX_CM` |

The hold-then-unwind curve (the same shape as in parking):
```python
progress = self._stage_progress(out_cm)                # 0.0 … 1.0 through the leg
if progress <= hold_pct:
    steer = sharp_steer                                # hold full angle
else:
    unwind_p = (progress - hold_pct) / max(0.01, 1.0 - hold_pct)   # 0…1 over the rest
    steer = sharp_steer + (config.SERVO_CENTER - sharp_steer) * (unwind_p ** 1.5)
#                                                         ** is "to the power of"
```

### Red is the master, Green is the mirror
Every dodge angle is **written once, for Red**, and passed through `_as_red()`:
```python
def _as_red(self, red_angle):
    tc = self._straight_servo()                                 # 87, the TRUE straight
    limit = min(tc - config.SERVO_MIN, config.SERVO_MAX - tc)   # same max lock both ways
    delta = max(-limit, min(limit, red_angle - tc))             # signed offset from straight
    return tc + (-delta if self.pillar_color == "Green" else delta)
```
Red 135 is 48° right of 87, so Green is 48° left of 87, which is 39. It is
**not** `180 - 135 = 45`, because mirroring about 90 made Green 6° softer and
it clipped pillars. **If you add a new dodge angle, write it for Red and wrap
it in `_as_red()`.**

### Leg lengths
```python
_out_cm()  = _leg_cm()                     # dodge_short_cm or dodge_long_cm (wide) or pixel method,
                                           #   + dodge_red_extra_cm, clamped 5..100
_past_cm() = dodge_past_cm + dodge_past_red_extra_cm
_in_cm()   = _leg_cm() + dodge_return_extra_cm + dodge_return_red_extra_cm
```

> **Check your copy:** in commit `5a1de4d`, `_past_cm()` reads
> `cm = config.DODGE_PAST_CM`, which means **the `dodge_past_cm` slider does
> nothing**. The fix (not yet committed when this was written) is
> `cm = float(p.get("dodge_past_cm", config.DODGE_PAST_CM))`.

### Pixel method (`pixel_distance_method.py`)
```python
sideways_cm = BASE_CM + toward_px * CM_PER_PIXEL       # 31.15 + px * 0.08, clamped 8..55
```
`toward_px` is how far the pillar sits **towards the side the car dodges to**.
A Green that is far LEFT needs a bigger swing left. A Green already on the
right needs less. When `use_pixel_dodge` is on, this replaces the wide/normal
split for the turn-out leg only.

---

# Part 3: parking + obstacle round combined

### What changed & how both codes are integrated

In `flasher.py`, two modes drive the car autonomously with the Pi:
- `"parking"` runs [`parking/parking_master.py`](parking/parking_master.py) with `open_slave.ino` on the ESP32 to test the parking exit on its own.
- `"obstacle"` runs [`obstacle_round/pi/main.py`](obstacle_round/pi/main.py) with `open_slave.ino` on the ESP32.

In this repository, we have the code that **integrates both of these codes together**:
[`obstacle_round/pi/main.py`](obstacle_round/pi/main.py). Instead of stopping after the exit,
the parking maneuver is incorporated directly as the **first phase of the obstacle round**,
sharing the exact same `open_slave.ino` ESP32 slave firmware. One START press does this:

```
START → lock lap direction from the walls → PARKING EXIT (4 steps) → hand over → 3 laps with pillars
```

**Nothing needs reflashing.** Both standalone parking and the integrated obstacle
round use the standard `open_slave.ino` firmware. The ESP32 streams sensor telemetry
and executes the speed/steering commands calculated by `main.py`.

### 3.1 Standalone Parking → Integrated `main.py` translation table

| Standalone (`parking_master.py` / concepts) | Integrated (`main.py`) | Note |
|---|---|---|
| `exit_dir` (+1 right, -1 left) | `self.lock` (+1 CW, -1 CCW) | **The same variable.** Wall on the left → exit right → lap is clockwise → corners are right turns. One reading decides both. |
| `start_yaw` | `self.park_hdg0 = d["yaw"]` | Starting reference heading |
| `start_ticks` / `self.stage_ticks0` | `self.park_ticks0 = self.ticks` | Encoder reference for stage travel |
| `wrap180(yaw - start_yaw)` | `_park_turned(d)` = `self.lock * heading_error(d["yaw"], self.park_hdg0)` | Positive in the exit direction |
| `abs(ticks - stage_ticks0) / TICKS_PER_CM` | `_park_gone()` = `abs(self.ticks - self.park_ticks0) / TICKS_PER_CM` | Distance traveled in the current step |
| `config.SERVO_CENTER` (87) | `self._straight_servo()` (90 + trim) | True straight steering angle |
| `config.STEER_LOCK_DEG` (50) | `park_steer_deg` (50 on the car per PARAMS.html; fallback 53) | Sharp steering angle offset |
| 90° target across lane | `park_turn_deg` 90 | Exit swing angle |
| `config.FORWARD_CM` / `STRAIGHT_CM` | `park_forward_cm` (**80** on the car per PARAMS.html; fallback 30) | Straight forward leg |
| Reverse leg | `park_back_cm` 20 | Reverse straight before straightening up |
| `config.EXIT_SPEED` (75) | `park_speed` (90 on dashboard) | Motor PWM speed during parking |
| `ParkingController.step()` stages | `self.park_step` going 1 → 2 → 3 → 4 → 0 | Tick-based state machine (~50 Hz) |
| STOP button handling | Handled by `main()` for the entire run | Cuts throttle and resets state |
| `STAGE_TIMEOUT_S` (14 s) | `park_max_cm` (400 cm): failsafe | If IMU stalls, ends parking after 4 m and races anyway |
| (always enabled) | `park_enabled`: 0 = skip parking | Dashboard toggle to test laps without parking |

`tools/park_exit_test.py` **verifies that these parameters and step sequences work correctly.**
If you change one side, update the test to match.

### 3.2 The new state variables (`__init__`, line 170)

```python
# Parking exit, run once before the round proper. park_step 0 = not in it.
self.park_step = 0          # 0 = off, 1 swing out, 2 forward, 3 back, 4 swing back
self.park_hdg0 = 0.0        # heading when parking began
self.park_ticks0 = 0        # encoder count when the CURRENT step began
```

### 3.3 Arming it: `begin_parking()` (line 425)

It is called once from `main()`, **after** `lock_direction_from_parking()`
(because it needs `self.lock`) and **after** `ctl._params` is set (because it
reads the park sliders):

```python
ctl = ObstacleRound(d["yaw"], now)
ctl.lock_direction_from_parking(d)          # sets self.lock from the walls
ctl._params = link.latest_params() or {}    # sliders available BEFORE the first step()
ctl.begin_parking(d, now)
```

```python
def begin_parking(self, d, now):
    if not self._park("park_enabled", 1.0):     # 0 → skip
        return
    self.park_step = 1
    self.park_hdg0 = d["yaw"]
    self.park_ticks0 = d.get("ticks") or self.ticks
```
`d.get("ticks") or self.ticks` means "the ticks from this DATA line, or if
that is None or 0, what we already had".

`_park()` is the safe slider reader:
```python
def _park(self, key, fallback):
    try:    return float((self._params or {}).get(key, fallback))
    except (TypeError, ValueError): return fallback
```

### 3.4 The four steps: `_park_step()` (line 457)

It runs once per tick. It returns `(speed, steer)` while parking, or `None` when finished.

```python
turn_deg = self._park("park_turn_deg", 90.0)
lock_deg = self._park("park_steer_deg", 53.0)
speed    = int(self._park("park_speed", self.turn_speed()))
turned   = self._park_turned(d)

if self._park_gone() > self._park("park_max_cm", 400.0):   # failsafe
    self.park_step = 0
    return None
```

**Step 1: swing out** (this is `swingTo(TURN_DEG, true, turnDir)`):
```python
if self.park_step == 1:
    if turned >= turn_deg:                               # threshold CROSSING
        self.park_step, self.park_ticks0 = 2, self.ticks # next step, new distance reference
    else:
        return speed, clamp_servo(self._straight_servo() + self.lock * lock_deg)
```
Notice there is **no `return` after moving to step 2**. The code falls through
into the `if self.park_step == 2:` block **in the same tick**, so no tick is
wasted sending nothing.

**Step 2: forward, holding the swung heading** (this is `straight(FORWARD_CM, TURN_DEG, true)`):
```python
if self.park_step == 2:
    want = self._park("park_forward_cm", 30.0)
    if self._park_gone() >= want:
        self.park_step, self.park_ticks0 = 3, self.ticks
    else:
        err = turn_deg - turned
        return speed, clamp_servo(self._straight_servo()
                                  + self.lock * max(-20.0, min(20.0, 1.2 * err)))
```
`max(-20, min(20, 1.2*err))` is Python's version of `constrain(HOLD_KP*err, -20, 20)`.

**Step 3: back up, holding the same heading** (this is `straight(BACK_CM, TURN_DEG, false)`):
```python
        return -abs(speed), clamp_servo(self._straight_servo()
                                        - self.lock * max(-20.0, min(20.0, 1.2 * err)))
#              ^^^^^^^^^ negative = reverse               ^ MINUS: reversing flips steering
```

**Step 4: swing back to square** (this is `swingTo(0, false, -turnDir)`):
```python
if self.park_step == 4:
    if turned <= 0:
        self.park_step = 0
        return None                        # ← finished
    return speed, clamp_servo(self._straight_servo() - self.lock * lock_deg)
```

> **Why `_park_gone()` is a function and not a variable:** when a step finishes,
> it resets `park_ticks0`, and the next step runs **in the same tick**. A
> distance worked out once at the top of the tick would still hold the old
> step's distance, and the next leg would "finish" instantly.

### 3.5 The handover inside `step()` (line 1219)

```python
if self.park_step:                      # non-zero = parking in progress
    out = self._park_step(d, now)
    if out is not None:
        self.last_t = now
        return out                      # parking owns the car: no corners, no pillars
    # --- parking just finished, on THIS tick ---
    self.target = d["yaw"]              # re-zero the round's heading to where the car points NOW
    self.i_term = 0.0
    self.pillar_stage = None
    self.pillar_clear_t = now           # ignore pillars for pillar_clear_delay_s
```

This block sits **above** everything else in `step()` (only `DONE` comes
before it), which is what gives parking absolute priority. When
`_park_step()` returns `None`, the code falls through into normal driving **in
the same tick**.

`self.target = d["yaw"]` matters because the round was started with
`ObstacleRound(d["yaw"], ...)` while the car sat in the bay. After the exit,
the car is square again but might be a few degrees off, so the straight-line
heading is reset to where it actually points.

### 3.6 Testing the merge without the car

```bash
cd obstacle_round/pi
python3 tools/park_exit_test.py
```
This simulates the car with a simple model and checks all of the following:
both mirror images, that the steps run 1→2→3→4 in order, that it ends square,
that overshooting 90° still ends the swing, that the 400 cm failsafe works,
that `park_enabled = 0` skips it, and **that the numbers match the `.ino`**.
The last line should say `ALL PASS`.

---

# Part 4: every parameter, explained

This part covers **every value you can tune**: what it does, the formula that
uses it, which way to move it, and what it interacts with. It is split into:

- **[4.1 Quick answers: "I want the car to …"](#41-quick-answers-i-want-the-car-to-)**: start here at the track
- **[4.2 How parameters work](#42-how-parameters-work-read-once)**: read this once
- **[4.3–4.11 The sliders, group by group](#43-group-0--leaving-the-parking-bay)**: every slider, in the same order as the dashboard
- **[4.12 Constants in `config.py`](#412-constants-in-configpy-no-slider-edit--deploy)**: settings with no slider, which need a code edit
- **[4.13 Parameters that do nothing](#413-parameters-that-do-nothing-right-now-traps)**: traps to avoid
- **[4.14 The reference docs win](#414-the-reference-docs-win)**: PARAMS.html and SPEC are authoritative

"Current" values are from `obstacle_round/pi/params.json` in the repo. **Where
[`docs/PARAMS.html`](docs/PARAMS.html) or [`SPEC.md`](SPEC.md) give a different value, theirs is the one to use (see 4.14).**
`deploy.sh` copies the Pi's file back into the repo each time it runs, so this
is the last tuning that was saved. Where `params.json` has no entry, the
default from `config.DEFAULT_PARAMS` applies, and it is marked *(default)*.

The group names (**0 · Leaving the parking bay** and so on) and the slider
ranges come from the new dashboard layout in `param_ui.py`. An older dashboard
may arrange things differently, but **the key names are the same.**

---

## 4.1 Quick answers: "I want the car to …"

Go through the list **in order** and change **one thing at a time**. Each
arrow shows which way to move the slider.

### Parking exit
| I want… | Change | Direction |
|---|---|---|
| Skip parking (testing laps) | `park_enabled` | **OFF** |
| Get further out into the lane before the round starts | `park_forward_cm` | ↑ (5–10 cm steps) |
| Stop hitting the bay wall when swinging out | `park_steer_deg` ↑ (tighter), then `park_turn_deg` ↓ | |
| Stop hitting the back wall when reversing | `park_back_cm` | ↓ |
| End more exactly parallel | Nothing in parking. The round re-zeroes the heading on handover. If it looks skewed, check `servo_trim_deg`. | |
| Park slower / more carefully | `park_speed` | ↓ (not below ~80, or the motor stalls) |

### Corners
| I want… | Change | Direction |
|---|---|---|
| Turn **earlier** (hits the wall / turns too late) | `front_turn_cm` | ↑ |
| Turn **later** (turns before reaching the corner) | `front_turn_cm` | ↓ |
| Finish the corner more tightly | `corner_steer_deg` ↑. But above ~35 the tyres scrub and it turns *worse*. | |
| Stop the tyres scrubbing / car not rotating in the turn | `corner_steer_deg` | ↓ |
| More room before turning (car is too close to the wall) | `pre_turn_reverse_cm` ↑, or `front_turn_cm` ↑ | |
| Let the reverse do more of the turn | `reverse_arc_leave_deg` ↓ | ↓ = the reverse does more |
| Reverse arc swings too little / too much | `reverse_arc_deg` | ↑ more / ↓ less |
| Car backs into the outer wall after a corner | `post_turn_reverse_cm` ↓, or `reverse_speed` ↓ | |
| More run-up on the new straight | `post_turn_reverse_cm` | ↑ |
| **Wrong lap direction** | Check where it's parked first. `default_lap_dir` is only a fallback. | |
| Car turns 90° **into a pillar** | `block_no_corner_s` ↑ and/or `block_near_cm` ↑ | |
| Car **misses a real corner** just after passing a pillar | `block_no_corner_s` | ↓ |

### Pillars
| I want… | Change | Direction |
|---|---|---|
| Start dodging **earlier** (it gets too close) | `pillar_trigger_dist_cm` ↑. **Above 35**, also raise `BACKOFF_TARGET_CM` (see 4.4). | |
| Start dodging later | `pillar_trigger_dist_cm` | ↓ |
| Clips the pillar on the **way out** | `pixel_base_cm` ↑ (if picture mode is ON, which it is), or `pillar_steer_right` ↑ (sharper) | |
| Swings out **too far** (hits the outer wall) | `pixel_base_cm` ↓, or `pillar_steer_right` ↓ | |
| Clips it only when the pillar is **off to one side** | `pixel_cm_per_px` ↑ | |
| Clips the pillar **alongside** / turns back in too early | `dodge_past_cm` ↑ (see the trap in 4.13), or `dodge_past_red_extra_cm` ↑ | |
| Clips it on the **way back in** | `dodge_return_extra_cm` ↓ (shorter swing back), or `dodge_align_min_red_cm` ↑ | |
| Ends up **across the lane** after a dodge (over-rotated) | `dodge_return_reduce_deg` ↑, or `dodge_return_extra_cm` ↓ | |
| Doesn't get back to the middle after a dodge | `dodge_return_extra_cm` ↑, or `recenter_k` ↑ | |
| Dodge is too violent / sudden | `turn_hold_pct` ↓ | |
| Doesn't get out sideways fast enough | `turn_hold_pct` ↑ | |
| **Dodges the same pillar twice** | `pillar_clear_cm` ↑ | |
| Ignores a pillar right after a dodge | `pillar_clear_cm` ↓, `pillar_clear_delay_s` ↓ | |
| Distance on the dashboard is wrong vs a tape measure | `pillar_focal_px` (see 4.4 for the formula) | |
| **Green behaves differently from Red** | Tune the **red** value. Green is mirrored from it automatically. | |

### Straights
| I want… | Change | Direction |
|---|---|---|
| Stop weaving / zig-zagging on straights | `cruise_wall_k` | ↓ (try 1.0, then 0.6) |
| Pure gyro, ignore the walls on straights | `cruise_wall_k` | **0** |
| Stay more in the middle | `cruise_wall_k` | ↑ |
| Car drifts to one side with the walls ignored | `servo_trim_deg` (see 4.10) | |
| Hold a different distance off the wall | `recenter_target_cm` (**not** `cruise_target_cm`, see 4.10) | |
| Go faster / slower | `base_speed` (max 110) | |

---

## 4.2 How parameters work (read once)

**Where they live.** Every tunable is a key in `config.DEFAULT_PARAMS`, which
holds the default. `params.json` on the Pi holds the tuned value. The dashboard
sliders write to it.

**Live vs saved.** Moving a slider sends the new value to `main.py`
**immediately**, even in the middle of a run. It is only written to
`params.json` when you click **Save to Disk**. If you don't save, the change is
lost when the Pi reboots.

**When a value takes effect.** Most are read **every tick**, so a change applies
on the next tick. Some are **latched** when a manoeuvre starts:
- `park_*` are read every tick, but changing them mid-exit is asking for trouble.
- `use_pixel_dodge`, `pixel_*`: read **once, when a dodge commits**.
- `pillar_trigger_dist_cm`: every tick of APPROACH.

**Green mirrors red.** When params are loaded or saved,
`config.mirror_green()` overwrites every green value from its red one:

| Green key (ignored) | Copied from |
|---|---|
| `pillar_steer_left` | mirror of `pillar_steer_right` about true straight (87) |
| `dodge_green_extra_cm` | `dodge_red_extra_cm` |
| `dodge_past_green_extra_cm` | `dodge_past_red_extra_cm` |
| `dodge_return_green_extra_cm` | `dodge_return_red_extra_cm` |
| `dodge_align_min_green_cm` | `dodge_align_min_red_cm` |

That is why `params.json` can say `dodge_green_extra_cm: 2.0` while the car
actually uses red's `6.0`. **The red names really mean "both colours".**

**Clamps.** `main.py` limits every value, so a typo cannot do anything wild.
Speeds are limited to 0..`MAX_PWM` (110), dodge legs to 5..100 cm, reverses
to 0..150 cm, and steering to the servo range 30..140. If a slider "stops
working" past a certain value, it has hit one of these limits.

**Two different "centres".** `config.SERVO_CENTER` is **90**. True straight is
**90 + `servo_trim_deg`**, which is **87**. Parking, cruising, reversing and
the dodge angles use 87. **Corner steering and the reverse arc use 90.** Keep
this in mind when you do the arithmetic.

---

## 4.3 Group 0 · Leaving the parking bay

Runs once at START, before the first lap (see Part 3). The car turns away from
the nearer wall. `lock` = +1 (turning right) or -1 (turning left).

### `park_enabled`: ON (default 1)
`begin_parking()` returns without doing anything when this is 0, so the round
starts driving from where the car stands. The lap direction is **still** read
from the side walls, so for testing, place the car nearer the correct wall.

### `park_turn_deg`: 90° (default) · range 30–120
How far to swing out (step 1 ends when `turned >= park_turn_deg`). The same
number is also the heading held during steps 2–3. Step 4 always swings back to
**0**, so the car ends on its starting heading whatever this is set to.
- ↓ to 60–70 for a shallower, longer exit. It needs more `park_forward_cm` to get clear.
- The swing ends on a **threshold crossing**, so it will overshoot by a few degrees at speed. That is expected.

### `park_steer_deg`: **50 on the car** (PARAMS.html) · fallback 53 · range 10–55
Wheel lock for both swings: `servo = 87 ± 50` = **137 / 37**. 53 is the
maximum (87 + 53 = 140); anything larger gets clamped at 140 on the right.
- ↓ = a wider circle, which needs more room in the bay.

### `park_forward_cm`: **80 cm on the car** (PARAMS.html / SPEC) · fallback 30 · range 0–200
Step 2: drive forward this far (encoder), holding `park_turn_deg` with
`steer = 87 + lock × clamp(1.2 × error, ±20)`.
This is the leg that carries the car clear of the bay into the lane. Raise it if
the car is still too close to the wall when the round starts.

### `park_back_cm`: 20 cm (default) · range 0–100
Step 3: reverse this far, holding the same heading. The correction sign is
flipped (Part 0.2). **This is blind**, because there is no rear sensor.

### `park_speed`: 90 PWM (default) · range 40–100
Used for all four steps. Below ~80 the motor may not move at all, and the
car sits there until `park_max_cm`… which never counts up, because it isn't
moving.

### `park_max_cm`: 400 cm (default) · range 100–800
**This is a failsafe, not a control.** If any single step has covered more
than this distance without finishing, the IMU is probably dead, so the car
gives up on parking and starts racing. A normal step is well under 1 m.

---

## 4.4 Group 1 · Seeing a pillar

### `pillar_focal_px`: 443.8 · range 200–1500
The camera focal length in pixels. Every pillar distance is
**`dist_cm = pillar_focal_px × 10 / box_height_px`** (or `× 5 / box_width` for a clipped box).
- **Calibrate it**: put a pillar at exactly 40 cm, read the distance on the dashboard, then
  `new = old × 40 / shown`. If it shows 50 at a real 40 cm: `443.8 × 40/50 = 355`.
- It is tied to the frame width. If `CAMERA_SIZE` changes (it is 640×360 now), this **must** be rescaled, along with `pixel_cm_per_px` and `ROI_CENTER_SHRINK_PX`.
- Every distance-based pillar setting below assumes this is correct. **Check this first** if the pillar behaviour seems off.

### `pillar_trigger_dist_cm`: 30 cm · range 5–120
**The activation distance.** When the camera distance is ≤ this for **3
separate camera frames** (`DODGE_TRIGGER_FRAMES`), the dodge commits. There is
also a shortcut: if the pillar is in the CENTER band, the front ToF reads
≤ 40 cm, and the ToF and camera agree within 25 cm, it commits immediately.
- ↑ = dodges start further away, for a gentler dodge with more room, but the pixel measurement is less precise.
- **Interaction with BACKOFF**: if a pillar is first seen closer than `trigger − 8` cm (`BACKOFF_IMMEDIATE_CM`), the car **reverses until it reads 35 cm** (`BACKOFF_TARGET_CM`), then approaches again. If you raise the trigger above ~35, the back-off stops *inside* the trigger and the car shuffles back and forth (twice, up to `BACKOFF_MAX_TRIES`). **When you raise the trigger, set `BACKOFF_TARGET_CM` in `config.py` to about trigger + 5.**
- The pixel calibration (4.6) was done at this distance. Changing it a lot makes `pixel_cm_per_px` less accurate.

---

## 4.5 Group 2 · The dodge: how hard

All angles are **written for Red** (dodging right) and mirrored for Green
about 87 by `_as_red()`. The largest offset either way is 53°
(`min(87−30, 140−87)`), so both colours run out of lock at the same point.

### `pillar_steer_right`: 135 · range 90–140
The **sharp turn-out angle**. Red: 135 is **48° right** of 87. Green: 87 − 48 = **39**.
- ↑ = sharper swing out. It gets sideways faster over the same distance.
- It also sets the **return angle**. The swing back in uses the mirror, `180 − 135 = 45` (red), i.e. 42° the other way.

### `pillar_steer_left`: *derived*, read-only
Shown for information. Changing it does nothing.

### `turn_hold_pct`: 30% · range 0–80
The shape of both the turn-out and the swing back in. For the first 30% of the
leg the wheels **hold** the sharp angle, then they unwind to straight over the
remaining 70% along a curve (`unwind^1.5`):
```
steer = sharp + (90 − sharp) × ((progress − 0.30) / 0.70) ^ 1.5
```
- ↑ = more time at full lock, so the car moves sideways faster and more abruptly.
- ↓ = starts easing off sooner, so the arc is smoother but gains less sideways.

### `dodge_wide_steer_deg`: 60 (default) · range 20–80
Only used for a **"wide" dodge**, which is a pillar already sitting on the side
the car is moving towards (Green in the LEFT band, Red in the RIGHT band). It
replaces `pillar_steer_right` with a **gentler** angle. It is written as the
green-side angle: red = 180 − 60 = **120** (33° right of 87), green = **54**.
- ↑ (towards 90) = gentler; ↓ = sharper.
- ⚠️ With picture mode ON (as it is now), the wide dodge uses this **gentle angle with the pixel-sized length**. The gentle angle was designed to go with the longer `dodge_long_cm` leg, so wide dodges may not get out far enough. If wide dodges clip, lower this towards 50.

### `block_offset_sens`: 0.8 · range 0–1.5
Fine-tunes the turn-out **angle** by where the pillar sits in the frame:
```
red_angle = pillar_steer_right + (±1) × norm_x × block_offset_sens × 15
norm_x = (pillar_cx − 320) / 320     # −1 at the left edge, +1 at the right edge
```
At 0.8 the most it can change is **±12°**. A Red pillar right of centre → sharper right.
- 0 = off.
- This adjusts the **angle**. The pixel method (4.6) adjusts the **distance**. Both are active at once, so if dodges get extreme on off-centre pillars, lower this first.

---

## 4.6 Group 3 · The dodge: leg lengths

A dodge has four legs, all measured on the encoder:
```
TURN_OUT (_out_cm) → STRAIGHTEN (_past_cm) → RECENTER (_in_cm) → ALIGN (until square)
```

### How the turn-out length is chosen
```python
if use_pixel_dodge and the pillar box is known:        # ← ON right now
    out = pixel_base_cm + toward_px × pixel_cm_per_px   (clamped 8..55, then 5..100)
    # dodge_short_cm, dodge_long_cm and dodge_red_extra_cm are NOT used
else:
    out = (dodge_long_cm if wide else dodge_short_cm) + dodge_red_extra_cm
```

### `use_pixel_dodge`: ON · switch
The master switch for **picture mode**. ON = the turn-out length comes from
where the pillar is in the frame. OFF = the fixed short/long lengths below.
Turn it OFF if the pixel sizing seems random. That usually means
`pillar_focal_px` or the trigger distance has changed since calibration.

### `pixel_base_cm`: 31.15 · range 0–40
The turn-out length for a pillar **dead centre** in the frame. It is **not** a
minimum: a centred pillar needs the most careful clearance.
- ↑ = every dodge swings out further, especially centred ones.

### `pixel_cm_per_px`: 0.08 · range 0–0.25
Extra turn-out per pixel that the pillar sits **towards the side the car is
dodging to**:
```
toward_px = (pillar_cx − 320)   for Red   (pillar further RIGHT → more)
toward_px = (320 − pillar_cx)   for Green (pillar further LEFT  → more)
out = 31.15 + toward_px × 0.08
```
Examples: a red pillar at cx = 420 → 31.15 + 100×0.08 = **39 cm**. At cx = 220
(already on the left, correct side) → 31.15 − 8 = **23 cm**.
- ↑ = more difference between centred and off-centre pillars.
- It is only valid for a **640-wide frame at the trigger distance** it was measured at.

### `dodge_short_cm`: 29 · `dodge_long_cm`: 35 · `dodge_red_extra_cm`: 6
Fixed-mode turn-out lengths: normal / wide, plus a trim. **These do nothing
while `use_pixel_dodge` is ON** (the code returns before reaching them).

### `dodge_past_cm`: 50 · range 5–90 · plus `dodge_past_red_extra_cm`: 5
STRAIGHTEN: how far to drive straight past the pillar, holding heading on the
gyro **with the ToF ignored** (the inner sensor is looking at the pillar).
`past = dodge_past_cm + per-colour extra`. On the car (SPEC): **Green 62 cm, Red 57 cm**.
- ↑ if the car clips the pillar as it turns back in (it turns in too early).
- ⚠️ **In committed `main.py` (`5a1de4d`) the `dodge_past_cm` slider is ignored.** The code uses `config.DODGE_PAST_CM` (52). Only the `_extra` slider works until the fix is committed (see Part 2.10).

### `dodge_return_extra_cm`: 3 · plus `dodge_return_red_extra_cm`: 0
RECENTER (swing back in): `in = turn-out length + 3 + 0`. The extra is added
**on top of whatever the turn-out was**, pixel mode included, so these always
work.
- ↑ = swings back in for longer, ending closer to the middle (or across it).
- ↓ = comes back in less.
- The two sliders do exactly the same thing. `_red_extra` is just a second slider for it.

### `dodge_return_reduce_deg`: 0 · range 0–30
Makes the swing-back-in angle **shallower**. The return angle is the mirror of
the turn-out (red: 45), moved towards straight by this many degrees (never past 90).
- ↑ if the car over-rotates across the lane on the way back in.

The swing back in also doesn't unwind all the way to straight. It ends at
`DODGE_RETURN_END_DEG` (80 green-side → **100 red / 74 green**), leaning
slightly into the direction ALIGN will need.

### `dodge_align_min_red_cm`: 2 · range 0–20
ALIGN won't finish until the car has driven at least this far, even if it is
already square. This stops the dodge ending with the pillar still alongside.
- ↑ if the car clips the pillar right at the end of the dodge.
- ALIGN itself: `steer = 87 + 2.4 × heading_error + clamp(wall_error × recenter_k, ±40)`. It finishes when the heading is within 5° (`ALIGN_DONE_ERR_DEG`) **and** this minimum is met, or after `ALIGN_MAX_CM` (45).

---

## 4.7 Group 4 · After a dodge

### `pillar_clear_cm`: 60 cm · range 0–150
After a dodge finishes, the car must drive this far before it may pick **any**
new pillar. Without it, the camera picks up the pillar just passed (sitting
beside the car at ~20 cm) and dodges it again.
It also controls the **minimum pickup distance**: for `2 × pillar_clear_cm`
(120 cm) after a dodge, pillars closer than 45 cm are ignored
(`PILLAR_MIN_ACQUIRE_CM`). After that, only pillars under 15 cm are ignored.
Turning a corner resets this gate, since the old pillar is behind the corner.
- ↑ if it dodges the same pillar twice.
- ↓ if two pillars are close together and it misses the second one.

### `pillar_clear_delay_s`: 1.2 s · range 0–6
A timer on top of `pillar_clear_cm`, and **both** must pass. Mostly matters
if the encoder stops reporting.

---

## 4.8 Group 5 · Corners

The sequence: **drive → reverse arc → forward turn → straight reverse** (see Part 2.9).

### `front_turn_cm`: 37 cm · range 15–80
A corner starts when the front ToF reads ≤ this (with the lap direction
already locked from parking). This is **the** corner distance.
- ↑ = turns earlier, further from the wall.
- ↓ = turns later, closer to the wall.
- Also blocked when: a pillar is dead ahead (group 6), the car hasn't driven 20 cm since the last corner, or a dodge is in progress.

### `corner_steer_deg`: 28 · range 10–50
The **maximum** steering during the forward turn. The actual angle is:
```
off = min(corner_steer_deg, max(7, 0.55 × |heading_error|))
servo = 90 + off (right turn)  /  90 − off (left turn)
```
So with 90° to go it uses the full 28 (servo 118 / 62). As the car comes round
it eases off, down to 7° near the end. The turn ends when the heading is within
13° of the target (`TURN_DONE_ERR_DEG`), or after 6.5 s.
- ↑ = tighter corners, until the tyres start scrubbing (above ~35). **More is not always tighter.**
- `CORNER_KP` (0.55) and `CORNER_MIN_OFF_DEG` (7) are constants.

### `pre_turn_reverse_cm`: 35 cm · range 0–60
The **reverse arc** before the turn. The car reverses with the wheels turned
**the opposite way** (turning right → wheels left), so the nose swings towards
the new heading while it backs off the wall. It stops at whichever comes first:
the heading is within `reverse_arc_leave_deg` of the target, **or** it has
reversed this far, **or** 8 s have passed.
- 0 = no reverse arc. The car turns forward from wherever it is.
- ↑ = more room, but more blind reversing.

### `reverse_arc_deg`: 40 · range 0–55 (capped at 50)
How far the wheels turn during the reverse arc: servo **90 ∓ 40 = 50 / 130**.
- ↑ = the arc rotates the car more per cm reversed.

### `reverse_arc_leave_deg`: 35 · range 0–90
How many degrees of the 90° are **left for the forward turn**. The arc stops
once `|heading_error| ≤ 35`, so it does about 55° and the forward turn does
the last 35°.
- ↓ = the reverse does more of the corner. At 0 it would try to do the whole corner in reverse.
- ↑ = the forward turn does more.

### `post_turn_reverse_cm`: 40 cm · range 0–150
After the turn finishes, reverse **straight** this far (holding heading, with
the correction flipped), to get run-up on the new straight.
- 0 = off.
- ↓ if it backs into the wall behind. ↑ if it starts the new straight too close to the next pillar.

---

## 4.9 Group 6 · Block or corner?

The front ToF can't tell a pillar from a wall. These two settings stop the car
turning 90° into a pillar.

### `block_near_cm`: 60 cm · range 20–120
A Red or Green pillar **in the CENTER band** that the camera puts closer than
this counts as "the thing in front". Pillars in the LEFT or RIGHT bands never
count, because the front ToF can't be looking at them.

### `block_no_corner_s`: 0.8 s · range 0–6
For this long after such a sighting, **corners are blocked** completely. The
memory matters because up close the pillar fills or leaves the frame and
detection drops out, which is exactly when the wall logic would take over.
- ↑ if it turns into pillars.
- ↓ if it misses a real corner right after a pillar that sits near one.
- 0 = off.

---

## 4.10 Group 7 · Driving straight

The straight-line formula (from the working open round):
```
servo = (90 + servo_trim_deg) + 1.2 × heading_error + wall_term
wall_term:  both walls < 80 cm  → (right − left) × k × 0.5
            one wall             → hold `target` cm off it (the OUTER wall preferred)
            none                 → 0
```

### `cruise_wall_k`: 1.6 · range 0–5
`k` on the straights. At 1.6, with the car at L30 / R70 the wall term alone is
(70−30)×1.6×0.5 = **32°** of steering. That is strong.
- **The first setting to lower if the car weaves or scrubs.** Try 1.0.
- **0 = pure gyro**: holds heading only and ignores the walls.

### `recenter_target_cm`: 45 cm · range 30–60
⚠️ **Despite the name, this is the one-wall target for normal cruising**, and
for ALIGN after a dodge. The final cruise call in `step()` passes
`recenter_target_cm` as the target.
- It only applies when **one** wall is visible. With both visible, the car balances them, and this is ignored.

### `cruise_target_cm`: 42 cm · range 20–70
The one-wall target **only during APPROACH** (driving towards a tracked pillar)
and the **finish push**. For everyday cruising, use `recenter_target_cm`.

### `recenter_k`: 2.0 · range 0.1–5
Wall strength during **ALIGN** only (after the swing back in). It uses the
**outer** wall only: after a Green dodge it trusts the left, after a Red the
right. The ToF on the pillar side can still see the pillar. It is clamped to
±40°.
- ↑ = gets back to the middle faster after a dodge. Too high and ALIGN wobbles and runs out of distance.

### `servo_trim_deg`: −3 · range −15 to 15
Where "straight" really is: 90 + (−3) = **87**. Measured: the heading controller
settles at 87.1, and a reverse at 90 curves left.
- To re-measure: set `cruise_wall_k = 0`, drive a long straight, and read the average `steer` column in the CSV log. Trim = that − 90.
- It changes parking, cruising, reversing and every dodge angle. **It does not change corners** (those use 90).

### `default_lap_dir`: CW · CW / CCW
Used **only** when neither side ToF sees a wall at START (both > 80 cm), so the
parking position can't tell the direction. Normally the direction comes from
the parking position: **nearer the LEFT wall = CW = right turns**.

---

## 4.11 Group 8 · Speed

All three are clamped to `MAX_PWM` = 110. 90 PWM ≈ **26 cm/s**. Below ~80 the
geared motor moves in jerks or doesn't move at all.

| Key | Current | Used for |
|---|---|---|
| `base_speed` | 90 | Straights, APPROACH, every dodge leg, finish push |
| `turn_speed` | 90 | The forward part of a corner. Also `park_speed`'s fallback. |
| `reverse_speed` | 90 | Reverse arc, post-corner reverse, BACKOFF, the wedged reverse. **All blind.** |

Distances are measured on the encoder, so **changing speed does not change
the shape** of any manoeuvre. It changes timing: a faster car covers more
ground between camera frames (so it triggers later and closer) and overshoots
turns further. When you raise speed, expect to raise `pillar_trigger_dist_cm`
and `front_turn_cm` a little too.

---

## 4.12 Constants in `config.py` (no slider: edit + deploy)

These are `UPPER_CASE` names in `obstacle_round/pi/config.py`. Changing one
means: edit, `deploy.sh`, and the service restarts. **Only the ones worth
knowing are listed here.**

### Safety and hardware
| Constant | Value | Meaning / when to change |
|---|---|---|
| `MAX_PWM` | 110 | Speed ceiling. **Also change it in `open_slave.ino` and reflash** (recipe E). Team limit is 170. |
| `SERVO_MIN` / `SERVO_MAX` | 30 / 140 | Steering limits. The mechanical stops are 28/142. Don't widen. |
| `SERVO_CENTER` | 90 | The nominal centre. Use `servo_trim_deg` instead. |
| `TICKS_PER_METER` | 2078 | Encoder calibration. Re-measure with `esp/tick_m_calculate` after any wheel or gear change. **Every distance depends on it.** |
| `TELEMETRY_MAX_AGE_S` | 0.3 | Sensor data older than this → car stops. |
| `CAMERA_SIZE` | (640, 360) | Frame size. Changing it means rescaling `pillar_focal_px`, `pixel_cm_per_px`, `ROI_CENTER_SHRINK_PX`. |

### Race
| Constant | Value | Meaning |
|---|---|---|
| `TOTAL_TURNS` | 12 | 3 laps × 4 corners. |
| `FINISH_TIME_S` | 3.0 | Drive on for this long after corner 12, then stop. **Tune this so the car stops in the start section.** |
| `LOCK_DIRECTION_AT_START` | True | Lap direction from the parking position. False = decide at the first corner (old behaviour). |

### Corners
| Constant | Value | Meaning |
|---|---|---|
| `TURN_DONE_ERR_DEG` | 13 | Turn ends when within this many degrees of the target. ↓ = more exact, but slower to finish. |
| `TURN_TIMEOUT_S` | 6.5 | Turn gives up after this long. |
| `CORNER_KP` / `CORNER_MIN_OFF_DEG` | 0.55 / 7 | Corner steering = 0.55 × error, at least 7°, at most `corner_steer_deg`. |
| `MIN_TRAVEL_BETWEEN_TURNS_CM` | 20 | Must drive this far between corners (stops double-counting). |
| `CORNER_CRITICAL_FRONT_CM` | 25 | Below this, the 20 cm rule is skipped. The car must turn. |
| `REVERSE_START_CM` / `REVERSE_STOP_CM` | 12 / 20 | Mid-turn: if front < 12, reverse with opposite lock until front > 20. |
| `POST_TURN_REVERSE_TIMEOUT_S` | 8 | Backstop for both corner reverses. |
| `KP_REVERSE_HEADING` | 1.2 | Heading-hold strength while reversing. |

### Straights and sensors
| Constant | Value | Meaning |
|---|---|---|
| `KP_HEADING_CRUISE` | 1.2 | Servo degrees per degree of heading error on straights. ↑ = snappier heading hold, but it may oscillate. |
| `WALL_VALID_CM` | 80 | A side reading ≥ this = "no wall there". |
| `TOF_VOTE_S` / `TOF_VOTE_MIN_SAMPLES` | 0.25 / 6 | A 999 reading has to be confirmed over this window before it is believed. |

### Pillars
| Constant | Value | Meaning |
|---|---|---|
| `DODGE_TRIGGER_FRAMES` | 3 | Camera frames that must agree before a dodge commits. ↑ = fewer false triggers, but later. |
| `BACKOFF_TARGET_CM` | 35 | Back off until the pillar reads this far. **Keep it about 5 cm above `pillar_trigger_dist_cm`.** |
| `BACKOFF_IMMEDIATE_CM` | 8 | Back off at once if the pillar is this far inside the trigger. |
| `BACKOFF_GRACE_S` / `BACKOFF_MAX_TRIES` / `BACKOFF_MAX_CM` | 0.6 / 2 / 45 | Grace period, retries, and furthest reverse. |
| `APPROACH_LOST_S` | 1.5 | Give up on a pillar that hasn't been seen for this long. |
| `PILLAR_SWITCH_MARGIN_CM` | 20 | Switch to a different pillar if it's this much nearer. |
| `PILLAR_TOF_COMMIT_CM` / `BLOCK_TOF_AGREE_CM` | 40 / 25 | The ToF commit shortcut, and how closely camera and ToF must agree. |
| `ALIGN_DONE_ERR_DEG` / `ALIGN_MAX_CM` | 5 / 45 | ALIGN ends within 5°. It gives up (with a warning) after 45 cm. |
| `STAGE_TIMEOUT_S` | 6 | Every dodge stage gives up after this long, in case the encoder dies. |
| `DODGE_RETURN_END_DEG` | 80 | Where the swing back in unwinds to (green-side; red = 100). |
| `ROI_CENTER_SHRINK_PX` | −75 | Negative = a **wider** CENTER band. Bands are thirds of 640 = 213 px, so the centre is ~288 px wide. |
| `BLOCK_CONF` | 0.5 | Minimum YOLO confidence. ↑ if it sees phantom pillars, ↓ if it misses real ones. |
| `PILLAR_SKIP_WHEN_ALREADY_CLEAR` | False | True = don't dodge a pillar already on its correct side. Off: every pillar is dodged. |
| (in `main.py`) `kp_align = 2.4` | 2.4 | ALIGN's heading gain. Written as a literal inside the ALIGN block. |

---

## 4.13 Parameters that do nothing right now (traps)

| Parameter | Why it does nothing |
|---|---|
| Every **green** key (`pillar_steer_left`, `dodge_*_green_*`) | Overwritten from red by `mirror_green()`. |
| `dodge_short_cm`, `dodge_long_cm`, `dodge_red_extra_cm` | `use_pixel_dodge` is ON, and `_leg_cm()` returns before reaching them. Turn picture mode OFF to use them. |
| `dodge_past_cm` | In committed `main.py`, `_past_cm()` reads `config.DODGE_PAST_CM` (52) instead. Fixed in the uncommitted working copy. Once that is committed and deployed, it works. |
| `cruise_target_cm` during normal cruising | Normal cruising uses `recenter_target_cm`. This one only affects APPROACH and the finish push. |
| `recenter_target_cm` / `cruise_wall_k` when both walls are visible | With both walls in range, the car balances them, and the target is ignored. |
| Any key in `params.json` that is **not** in `DEFAULT_PARAMS` | `load_params()` drops unknown keys. |

---

## 4.14 The reference docs win

[`docs/PARAMS.html`](docs/PARAMS.html) and [`SPEC.md`](SPEC.md) /
[`docs/SPEC.html`](docs/SPEC.html) are **the authoritative reference** for
values and behaviour on the car. If this guide disagrees with them, **they
win**. This guide explains *how the code uses* each value. Those pages say
*what the value is and should be*.

Values where they differ from the `config.py` fallbacks quoted elsewhere in this guide:

| Parameter | PARAMS / SPEC (use this) | `config.py` fallback |
|---|---|---|
| `park_forward_cm` | **80 cm** | 30 |
| `park_steer_deg` | **50°** | 53 |
| Run past the pillar (`dodge_past_cm` + extra) | **Green 62 / Red 57 cm** | — |
| Swing back in | **Green turn-out + 6 / Red turn-out + 3** | — |

When you change a parameter, update PARAMS.html and republish it, as
[`docs/README.md`](docs/README.md) says.

---

# Part 5: how to change things safely (recipes)

Every recipe ends with the same three steps: **test → deploy → commit.**
```bash
python3 obstacle_round/pi/tools/park_exit_test.py     # and any other relevant test
pi_setup/deploy.sh                                     # copies code, restarts services; keeps params.json
git add -A && git commit -m "what and why" && git push
```

### A. Change a number that has a slider
1. Open `http://error404.local:8080`, move the slider, and try it. It applies instantly.
2. Click **Save to Disk** to write it to `params.json` on the Pi.
3. No code change is needed. `deploy.sh` copies the Pi's `params.json` back into the repo next time.

### B. Change the parking exit
1. In the combined round: use the `park_*` sliders on the dashboard (A), or edit `DEFAULT_PARAMS` in `obstacle_round/pi/config.py`.
2. To turn it off in the combined round: set `park_enabled` to 0.
3. For standalone parking testing: edit parameters in `parking/config.py` and run via `flasher.py parking` or `parking.service`.
4. If you change a default in `config.py`, verify that `python3 obstacle_round/pi/tools/park_exit_test.py` passes.

### C. Add a brand-new slider
1. Add the key and default to `DEFAULT_PARAMS` in `config.py`. **Without this, `load_params` drops it.**
2. Read it in `main.py` with the safe pattern:
   ```python
   try:
       v = float((self._params or {}).get("my_new_key", 12.0))
   except (TypeError, ValueError):
       v = 12.0
   v = max(0.0, min(50.0, v))       # always clamp
   ```
3. To make it appear on the dashboard, copy how an existing key such as `pre_turn_reverse_cm` is listed in `param_ui.py` (a list of `{"key": ..., "label": ..., "unit": ...}` entries).

### D. Change a constant (no slider)
1. Edit `config.py`.
2. Deploy. `master.service` restarts and picks it up.

### E. Change the maximum speed
1. Change `MAX_PWM` in `obstacle_round/pi/config.py`.
2. Change `MAX_PWM` in `obstacle_round/esp/open_slave/open_slave.ino`.
3. **Reflash the ESP32.** If you do only step 1, the ESP silently clips the speed back down.
4. The team limit is 170. Do not go over it.

### F. Corners are taken too early or too late
- Use the `front_turn_cm` slider. Higher = turn earlier.
- If the car turns but ends crooked, look at `TURN_DONE_ERR_DEG` (13°) in `config.py`. Smaller = finishes closer to the target.
- If it scrubs or does not rotate, use the `corner_steer_deg` slider. **Smaller** can actually turn better, because at full lock the tyres slide instead of gripping.

### G. The dodge clips the pillar
- On the way out: raise `pixel_base_cm` (picture mode, which is on), or `pillar_steer_right` (sharper). `dodge_red_extra_cm` only works with picture mode off.
- Passing: raise `dodge_past_red_extra_cm`.
- Coming back in: raise `dodge_return_extra_cm` (the return swing) or `dodge_align_min_red_cm`.
- **Tune the red values only.** Green copies them.

### H. Add a new stage to a state machine
1. Choose a name, e.g. `"WAIT"`.
2. Enter it from the previous stage with `self._begin_stage("WAIT", now)`. That resets `stage_cm`.
3. Add `if self.pillar_stage == "WAIT": ... return speed, steer` **in the right place in `step()`**. The position is its priority.
4. End it with `_stage_done(cm, now)` (distance, with a timeout backstop), then `_begin_stage("NEXT", now)`.
5. Add a line for it in `_stage_display_raw`, so the dashboard and CSV show it.

---

# Part 6: when it misbehaves, where to look

| Symptom | First place to look |
|---|---|
| Car does nothing after START | `journalctl -u master.service -f`. Is `dashboard.service` running? Is `DATA` arriving? Is the ESP LED blue or green? |
| Car stops after half a second, LED red | ESP watchdog: `main.py` crashed or stopped sending. Check the journal. |
| Wrong lap direction | The `PARKED DIRECTION:` log line. Was it parked nearer the correct wall? Is the ToF left/right swap right (ch1 = LEFT)? |
| Parking swings forever | IMU is not reading (BNO on mux ch4?). The 400 cm failsafe will end it. |
| A slider does nothing | Is the key in `DEFAULT_PARAMS`? Is it a green key (overwritten by red)? Does the code read the slider or a constant (see the `_past_cm` note)? |
| Speed change does nothing | `MAX_PWM` is capped on the ESP too (recipe E). |
| Car turns into a pillar | `CORNER BLOCKED` in the log. Check `block_near_cm` and `block_no_corner_s`. |
| Car dodges the same pillar twice | Raise `pillar_clear_cm`. |
| Any bad run | Open `logs/run_*.csv`. Every tick has the stage, decision, sensors, target, speed and steer. |

**Log lines worth searching for:** `RUN STARTED`, `PARKED DIRECTION`,
`PARKING 1/4` … `4/4`, `CORNER n: TURNING`, `CORNER n COMPLETE`,
`PILLAR DETECTED`, `STAGE 2: TURNING OUT`, `DODGE COMPLETE`, `BACKING OFF`,
`FINISH LINE CROSSED`.

**Before trusting any change:** put the car on a stand (wheels off the ground),
press START, and watch the dashboard. The steering should go the way you
expect before the car ever touches the mat.

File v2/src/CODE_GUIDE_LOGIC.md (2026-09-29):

# WRO 2026 Vehicle Logic Specification & Control Flow

This document provides the **exhaustive control logic, mathematical formulas, state machine transitions, and branching conditions** implemented in `obstacle_round/pi/main.py`. Use this specification to diagnose logical flaws, edge-case race conditions, and parameter mismatches without reading code line-by-line.

---

## 1. System Coordinates, Sign Conventions & Constants

All calculations in `main.py` follow these rigid mathematical definitions:

| Variable | Definition / Formula | Behavior & Range |
|---|---|---|
| **True Straight** | `SERVO_CENTER (87) = 90 + servo_trim_deg (-3)` | Neutral center steering angle. |
| **Steering Angle** | Clamped to `[SERVO_MIN, SERVO_MAX] = [30, 140]` | **$> 87$ = Wheels RIGHT**, **$< 87$ = Wheels LEFT**. |
| **Yaw / Heading** | BNO055 IMU in `[0.0, 359.9]` | **Clockwise = increasing yaw**. |
| **Heading Error** | `herr = (target - current + 180) % 360 - 180` | Normalizes to `[-180.0, +180.0]`.<br>**Positive ($>0$) = Must steer RIGHT**.<br>**Negative ($<0$) = Must steer LEFT**. |
| **Distance (cm)** | `abs(ticks - ref_ticks) / 20.78` | Encoder ticks: `TICKS_PER_CM = 20.78` ($2078\text{ ticks/m}$). |
| **Lap Lock (`self.lock`)** | `+1` (Clockwise) or `-1` (Anti-Clockwise) | **`+1` (CW)**: All corners are **RIGHT** turns.<br>**`-1` (CCW)**: All corners are **LEFT** turns. |
| **Dodge Direction** | `_dodge_sign() = +1` (Red) or `-1` (Green) | **Red**: Steers **RIGHT** first.<br>**Green**: Steers **LEFT** first. |
| **Reverse Polarity** | Inverts yaw rotation relative to wheel direction | When reversing, wheels angled right swing the nose left. **All reverse heading-hold formulas invert the correction sign (`-herr`).** |

---

## 2. Master Execution Hierarchy (`step()` Preemption Order)

`ObstacleRound.step(d, blocks, params, now)` runs at **50 Hz**. It evaluates actions strictly from top to bottom. **The first branch that matches takes total control of the car for that tick and returns `(speed, steer)`.**

```
[1. state == "DONE"] ──▶ Halt (0 PWM, 87°)
       │
[2. self.park_step != 0] ──▶ Execute Parking Exit (_park_step)
       │
[3. state == "FINISHING"] ──▶ Finish Line Push (3.0s past turn 12)
       │
[4. self.is_turning == True] ──▶ Execute Forward Turn (_turn_step)
       │
[5. self.pre_turn_reverse == True] ──▶ Reverse Arc Before Corner
       │
[6. self.post_turn_reverse == True] ──▶ Straight Reverse After Corner
       │
[7. Corner Check: _should_turn() == True] ──▶ Trigger Corner (if NOT mid-dodge)
       │
[8. Pillar Acquisition & Tracking] ──▶ Scan blocks, evaluate gates
       │
[9. self.pillar_stage == "BACKOFF"] ──▶ Reverse to restore trigger distance
       │
[10. self.pillar_stage == "APPROACH"] ──▶ Cruise straight, check commit gates
       │
[11. self.pillar_stage == "TURN_OUT"] ──▶ Dodge Leg 1: Steer lock & unwind
       │
[12. self.pillar_stage == "STRAIGHTEN"] ──▶ Dodge Leg 2: Drive past pillar
       │
[13. self.pillar_stage == "RECENTER"] ──▶ Dodge Leg 3: Return arc into corridor
       │
[14. self.pillar_stage == "ALIGN"] ──▶ Dodge Leg 4: Heading + wall squaring
       │
[15. Default] ──▶ Normal cruising with wall-centering P-controller
```

---

## 3. ToF Sensor De-Glitching Logic (`_deglitch_tof`)

The raw hardware streams `999` for both "out of range" and "hardware I2C timeout". Because an open side (`999`) can instantly lock lap direction or commit a corner, high readings are filtered through a temporal voting window:

- **Window Parameters:** Duration `TOF_VOTE_S = 0.2s`, minimum samples `TOF_VOTE_MIN_SAMPLES = 3`.
- **Low Reading ($0 < \text{dist} < 999$):** Passed through immediately without delay (ensures instant emergency braking).
- **High Reading ($\text{dist} \ge 999$ or $\le 0$):**
  - If `high_count * 2 > total_samples_in_window`: Passed through as genuine open space (`999`).
  - Otherwise: Replaced with the **median of real valid readings** in the window.
  - If no valid readings exist in window: Replaced with the last valid reading if younger than `TOF_HOLD_S = 0.35s`.

---

## 4. Lap Direction Determination (`lock_direction_from_parking`)

Determined **once** at the start of the round while parked in the bay.

### Direction Logic:
```python
left, right, ambiguous = self._lock_sides(d)
if ambiguous or left is None or right is None:
    self.lock = self._default_lock() # Read from param 'default_lap_dir'
elif left < right:
    self.lock = 1   # Wall on LEFT  -> Exits RIGHT -> Lap is CLOCKWISE (Right corners)
else:
    self.lock = -1  # Wall on RIGHT -> Exits LEFT  -> Lap is ANTI-CLOCKWISE (Left corners)
```
- **Side validity floor:** `WALL_VALID_CM = 130 cm`. Any reading $\ge 130\text{ cm}$ or $999$ is considered an open side.
- **Ambiguity Condition:** If `left >= 130` AND `right >= 130` (both sides read open), direction falls back to `default_lap_dir` (default: CW / `+1`).

---

## 5. Parking Exit State Machine (`_park_step`)

Active when `self.park_step in (1, 2, 3, 4)`.

- **Failsafe Limit:** If `_park_gone() > park_max_cm (400 cm)`, parking aborts immediately (`self.park_step = 0`), hands over to lap driving.
- **Exit Turn Measurement:** `turned = self.lock * heading_error(current_yaw, park_hdg0)`. (Always positive in the exit direction).

### Stage 1: Swing Out of Bay
- **Steering:** Full lock in exit direction: `87 + self.lock * park_steer_deg` (default $87 \pm 50^\circ$).
- **Exit Condition:** `turned >= park_turn_deg` (default $90^\circ$).
- **On Exit:** `self.park_step = 2`, `self.park_ticks0 = self.ticks` (resets distance counter; falls through to Step 2 in the same tick).

### Stage 2: Straight Forward Across Lane
- **Steering:** P-controller holds the $90^\circ$ exit heading:
  $$\text{steer} = 87 + \text{self.lock} \times \text{clamp}(1.2 \times (90 - \text{turned}), -20^\circ, +20^\circ)$$
- **Exit Condition:** `_park_gone() >= park_forward_cm` (car uses 80 cm per SPEC; default fallback 30 cm).
- **On Exit:** `self.park_step = 3`, `self.park_ticks0 = self.ticks`.

### Stage 3: Back Up Straight
- **Steering:** Inverted P-controller (reverse flips yaw rotation):
  $$\text{steer} = 87 - \text{self.lock} \times \text{clamp}(1.2 \times (90 - \text{turned}), -20^\circ, +20^\circ)$$
- **Speed:** `-abs(park_speed)` (negative PWM = reverse).
- **Exit Condition:** `_park_gone() >= park_back_cm` (default 20 cm).
- **On Exit:** `self.park_step = 4`, `self.park_ticks0 = self.ticks`.

### Stage 4: Swing Back Square to Corridor
- **Steering:** Opposite full lock: `87 - self.lock * park_steer_deg`.
- **Exit Condition:** `turned <= 0.0^\circ` (threshold crossing, not a window).
- **On Exit:** `self.park_step = 0`, returns `None`. Handover:
  - Re-zeros master target heading: `self.target = d["yaw"]`.
  - Sets `self.pillar_clear_t = now` (briefly suppresses pillar acquisition).
  - Control falls through to normal lap cruising in the same tick.

---

## 6. Corner Detection & Decision Logic (`_should_turn`)

Called every tick when `self.is_turning == False` and `dodge_running == False`.

### Gate 1: Close Pillar Suppression (Pillars are NOT corners!)
The front ToF cannot distinguish a pillar from a wall. To stop the car turning $90^\circ$ into a pillar:
1. If a pillar was detected in the `CENTER` ROI band with `dist <= block_near_cm` (default 60 cm):
   - Corners are **completely suppressed** for `block_no_corner_s` (default 2.5s) after the last close sighting:
     ```python
     if hold_s > 0 and self.block_near_centred and (now - self.block_near_t) <= hold_s:
         return False # Suppress corner!
     ```
2. If currently in `APPROACH` or `TURN_OUT` with `abs(front_tof - pillar_dist) <= BLOCK_TOF_AGREE_CM (25 cm)`:
   - Front ToF is overridden to `999.0` (treated as the pillar, not a wall).

### Gate 2: Inter-Turn Movement Floor
To prevent the car spinning in circles at a single corner:
- If `turns > 0` and front is NOT critically close (`front > CORNER_CRITICAL_FRONT_CM = 15 cm`):
  - Must have traveled `moved_cm >= MIN_TRAVEL_BETWEEN_TURNS_CM (100 cm)` since previous turn.
  - If encoder is dead: `now - last_turn_end > TURN_COOLDOWN_S (1.0s)`.
  - If traveled $< 100\text{ cm}$, returns `False`.

### Gate 3: Turn Trigger Distance (`front_turn_cm`)
Corner is triggered when:
$$0 < \text{front} \le \text{front\_turn\_cm (default 37 cm)}$$

### Gate 4: Direction Verification (If `self.lock` already fixed)
- If `self.lock == 1` (CW): Triggers if `d["right"] > SIDE_GAP_THRESHOLD_CM (55 cm)` OR `front <= EMERGENCY_FRONT_CM (40 cm)`.
- If `self.lock == -1` (CCW): Triggers if `d["left"] > SIDE_GAP_THRESHOLD_CM (55 cm)` OR `front <= EMERGENCY_FRONT_CM (40 cm)`.

### Gate 5: Unlocked Direction Handling (Lap 1 fallback)
If `self.lock == 0`:
1. Checks `_settled_after_dodge(d)`: requires `abs(ticks - dodge_end_ticks) >= LOCK_AFTER_DODGE_CM (45 cm)`.
2. Genuinely open side test: `really_right = (d["right"] >= 130)` vs `really_left = (d["left"] >= 130)`.
3. If both open or both closed: `_blind_lock_dir(d)` requires `abs(left - right) >= LOCK_MIN_MARGIN_CM (15 cm)` for `LOCK_CONFIRM_FRAMES (3)` consecutive frames.
4. Emergency fallback at `front <= 40 cm`: defaults to `default_lap_dir`.

---

## 7. Corner Execution Maneuver

Once `_should_turn()` returns `True`, execution branches into three phases:

### Phase A: Pre-Turn Reverse Arc (`pre_turn_reverse`)
Active if `pre_turn_reverse_cm > 0` (default 35 cm):
- **Calculates absolute target heading immediately:**
  $$\text{self.corner\_target} = (\text{self.target} + 90.0 \times \text{self.lock}) \pmod{360}$$
- **Steering:** Wheels turned **opposite** to turn direction:
  - If `self.lock == 1` (CW / Right turn): Steers **LEFT** (`87 - reverse_arc_deg = 87 - 40 = 47°`).
  - If `self.lock == -1` (CCW / Left turn): Steers **RIGHT** (`87 + reverse_arc_deg = 87 + 40 = 127°`).
  - This swings the front of the car toward the new heading while backing away from the wall.
- **Exit Conditions (Whichever happens first):**
  1. IMU error threshold met: `abs(heading_error(corner_target, yaw)) <= reverse_arc_leave_deg` (default 35° left for forward turn).
  2. Traveled distance: `moved >= pre_turn_reverse_cm` (35 cm).
  3. Failsafe timeout: `elapsed >= POST_TURN_REVERSE_TIMEOUT_S (3.0s)`.

### Phase B: Forward Corner Turn (`_turn_step`)
- **Target Heading:** `self.target = self.corner_target` (from arc) or $(\text{target} \pm 90^\circ)$.
- **Dynamic Proportional Steering (`_corner_steer`):**
  $$\text{error} = \text{abs}(herr)$$
  $$\text{offset} = \min(\text{corner\_steer\_deg (28°)}, \max(\text{CORNER\_MIN\_OFF\_DEG (12°)}, \text{CORNER\_KP (0.8)} \times \text{error}))$$
  $$\text{steer} = 87 + \text{offset} \quad (\text{if Right turn}), \quad 87 - \text{offset} \quad (\text{if Left turn})$$
  *(Angle eases off as heading approaches target, preventing tire scrub).*
- **Wedge Detection & 3-Point Recovery:**
  - If `0 < front < REVERSE_START_CM (15 cm)`: Sets `self.is_reversing = True`.
  - While reversing: `speed = -reverse_speed`, steers opposite lock to back away.
  - Clears reversing state once `front > REVERSE_STOP_CM (22 cm)`.
- **Exit Conditions:**
  $$\text{abs}(herr) < \text{TURN\_DONE\_ERR\_DEG (13°)} \quad \text{OR} \quad \text{elapsed} > \text{TURN\_TIMEOUT\_S (2.5s)}$$
- **On Completion:**
  - `self.turns += 1`
  - `self.dodge_end_ticks = None` (clears post-dodge suppression on new straight).
  - Arms `post_turn_reverse = True`.
  - If `self.turns >= TOTAL_TURNS (12)`: transitions to `state = "FINISHING"`.

### Phase C: Post-Turn Straight Reverse (`post_turn_reverse`)
- **Steering:** Closed-loop heading hold in reverse:
  $$\text{steer} = 87 - \text{KP\_REVERSE\_HEADING (1.0)} \times herr$$
- **Exit Condition:** `moved >= post_turn_reverse_cm` (default 40 cm) or timeout (3.0s).

---

## 8. Pillar Acquisition & Tracking Logic

Scanning occurs when `self.pillar_stage is None`, `not self.is_turning`, and `not self.pre_turn_reverse`.

### Acquisition Suppression Gates:
1. **Cooldown Gate:**
   - Traveled distance: `abs(ticks - dodge_end_ticks) >= pillar_clear_cm (50 cm)`.
   - Elapsed time: `now - pillar_clear_t > pillar_clear_delay_s (1.2s)`.
2. **Close-Floor Gate (Prevent re-adopting the pillar just passed):**
   - If `traveled < clear_cm * 2 (100 cm)`: Minimum acquire distance is `PILLAR_MIN_ACQUIRE_CM = 45 cm`.
   - Otherwise: Floor is `PILLAR_MIN_ACQUIRE_FLOOR_CM = 20 cm`.
   - Any pillar closer than floor is discarded.
3. **"Already Clear" Gate (`already_clear()`):**
   - Red pillar already in `LEFT` band (`cx < 320 - 75 = 245 px`).
   - Green pillar already in `RIGHT` band (`cx > 320 + 75 = 395 px`).
   - If pillar is already on its correct passing side, it is **ignored** (no dodge executed).

### Candidate Selection:
- Filter valid blocks (`Red` or `Green`), sort by `dist_cm` ascending: `valid[0]` is nearest.
- Adopt: Sets `pillar_stage = "APPROACH"`, records `pillar_color`, `pillar_dist`, `pillar_cx`.

### Dynamic Target Switching in `APPROACH`:
If another pillar of the **opposite** color is detected:
- Condition: `other_dist >= 45 cm` AND `self.pillar_dist - other_dist >= PILLAR_SWITCH_MARGIN_CM (20 cm)`.
- **Switches target immediately to the nearer pillar.**

---

## 9. Pillar Approach & Backoff State Machine

### 9.1 Backoff Logic (`BACKOFF`)
If a pillar is detected too close, dodging without room causes the car to sideswipe it or clip it while turning.
- **Trigger Conditions (Enters `BACKOFF`):**
  1. `pillar_dist < pillar_trigger_dist_cm (30) - BACKOFF_IMMEDIATE_CM (8) = 22 cm` (Immediately too close).
  2. `pillar_dist < 30 cm` continuously for `> BACKOFF_GRACE_S (0.6s)` without commit frames confirming.
- **Execution:** Reverses straight holding heading (`-reverse_speed`, `_reverse_hold_steer`).
- **Exit Conditions:**
  - `pillar_dist >= BACKOFF_TARGET_CM (35 cm)` $\rightarrow$ Returns to `APPROACH`.
  - Traveled `stage_cm >= BACKOFF_MAX_CM (45 cm)` $\rightarrow$ Stops reversing, forces `APPROACH`.
  - Max tries: `BACKOFF_MAX_TRIES = 2`.

### 9.2 Approach Logic & Commit Conditions
In `APPROACH`, the car cruises straight (`_straight`) waiting for the trigger:
- **Clipped-Box Protection:** If bounding box is clipped at frame edge and distance reports an increase `> PILLAR_DIST_GROW_CM (15 cm)`, the increase is rejected and the last valid distance is held.
- **Pillar Lost Timeout:** If pillar is not seen for `APPROACH_LOST_S (1.5s)`, drops approach and resumes cruising.
- **Trigger Condition (Commits to `TURN_OUT`):**
  - **Normal Path:** `trigger_frames >= DODGE_TRIGGER_FRAMES (3)` consecutive camera frames with `pillar_dist <= pillar_trigger_dist_cm (30 cm)`.
  - **Front ToF Fast-Commit Shortcut:**
    If pillar is centered, `0 < front_tof <= PILLAR_TOF_COMMIT_CM (40 cm)`, seen within `0.4s`, and `abs(pillar_dist - front_tof) <= BLOCK_TOF_AGREE_CM (25 cm)`:
    - **Instantly sets `trigger_frames = 3` and commits to `TURN_OUT` immediately.**

---

## 10. The 4 Dodge Stages

Once committed, `dodge_running == True`. **No corner can interrupt these stages.**

```
(Commit) ──▶ Stage 1: TURN_OUT ──▶ Stage 2: STRAIGHTEN ──▶ Stage 3: RECENTER ──▶ Stage 4: ALIGN ──▶ Cruise
```

### Stage 1: `TURN_OUT`
- **Lateral Distance Calculation (`_out_cm()`):**
  - If `use_pixel_dodge == True` (Default):
    $$\text{offset\_px} = \text{abs}(cx - 320) \quad \text{towards dodge side}$$
    $$\text{out\_cm} = \text{clamp}(\text{pixel\_base\_cm (31.15)} + \text{offset\_px} \times \text{pixel\_cm\_per\_px (0.08)}, 8.0, 55.0)$$
  - Else: `dodge_short_cm (29 cm)` or `dodge_long_cm (35 cm)` + `dodge_red_extra_cm`.
- **Steering Angle Calculation:**
  - Red Base: `pillar_steer_right (135°)`.
  - Off-center adjustment: `red_out = 135 + sign * norm_x * offset_sens * 15.0`.
  - Mirrored for Green via `_as_red()`:
    $$\delta = \text{clamp}(red\_angle - 87, -53, +53)$$
    $$\text{steer} = 87 - \delta \quad (\text{for Green}), \quad 87 + \delta \quad (\text{for Red})$$
- **Unwind Profile:**
  - For progress $0.0 \to \text{turn\_hold\_pct (0.30)}$: Holds full `sharp_steer`.
  - For progress $0.30 \to 1.0$:
    $$\text{unwind} = \frac{\text{progress} - 0.30}{0.70}, \quad \text{steer} = \text{sharp} + (87 - \text{sharp}) \times \text{unwind}^{1.5}$$
- **Exit Condition:** `self.stage_cm >= out_cm`.

### Stage 2: `STRAIGHTEN` (Running Past Pillar)
- **Target Distance:** `_past_cm() = dodge_past_cm (50 cm) + dodge_past_red_extra_cm`.
- **Steering:** Calls `_straight(d, now, ignore_tof=True)`:
  - **Ignores ToF entirely** because the inner side sensor is pointing directly into the pillar body.
  - Steers on pure IMU heading error: `steer = 87 + KP_HEADING_CRUISE (1.2) * herr`.
- **Exit Condition:** `self.stage_cm >= _past_cm()`.

### Stage 3: `RECENTER` (Turning Back into Corridor)
- **Target Distance:** `_in_cm() = _leg_cm() + dodge_return_extra_cm (6.0 cm) + dodge_return_red_extra_cm`.
- **Return Angle:** Mirrored from turn-out and softened by `dodge_return_reduce_deg` (so the car does not cross the lane):
  $$\text{red\_mirror} = 2 \times 87 - \text{red\_out}$$
  $$\text{red\_return} = \min(87, \text{red\_mirror} + \text{dodge\_return\_reduce\_deg (10°)})$$
  $$\text{sharp\_return} = \text{\_as\_red}(\text{red\_return})$$
- **Pre-rotated Unwind Target:**
  Unwinds not to 87°, but to `return_end = _as_red(2*87 - DODGE_RETURN_END_DEG)` ($80^\circ$ for Green, $100^\circ$ for Red), pre-leaning the wheels to square up.
- **Exit Condition:** `self.stage_cm >= _in_cm()`.

### Stage 4: `ALIGN` (Squaring Up)
- **Dual P-Controller:**
  $$\text{align\_steer} = 87 + \text{kp\_align (2.4)} \times herr$$
  $$\text{wall\_steer} = \text{clamp}(\text{wall\_err} \times \text{recenter\_k (1.5)}, -40^\circ, +40^\circ)$$
  $$\text{steer} = \text{align\_steer} + \text{wall\_steer}$$
- **Exit Conditions (Must satisfy BOTH or timeout):**
  1. `abs(herr) < ALIGN_DONE_ERR_DEG (5.0°)`
  2. `self.stage_cm >= _align_min_cm()` (Guarantees forward travel so rear bumper clears pillar before ending dodge).
  3. Failsafe timeout: `self.stage_cm >= ALIGN_MAX_CM (45 cm)`.
- **On Completion:**
  - `self.dodge_end_ticks = self.ticks` (Arms distance suppression for corners and new acquisitions).
  - Resets all pillar tracking variables to `None`.
  - Resumes normal cruise.

---

## 11. Normal Cruising & Wall Centering (`_straight`)

Active when no dodge and no corner is running:

$$\text{steer} = 87 + \text{KP\_HEADING\_CRUISE (1.2)} \times herr + \text{self.nudge}$$

### `self.nudge` Calculation:
- **Both Walls in Range ($< 130\text{ cm}$):**
  $$\text{nudge} = \text{cruise\_wall\_k} \times \frac{\text{left} - \text{right}}{2.0}$$
- **Only Left Wall in Range:**
  $$\text{nudge} = \text{cruise\_wall\_k} \times (\text{cruise\_target\_cm (42)} - \text{left})$$
- **Only Right Wall in Range:**
  $$\text{nudge} = -\text{cruise\_wall\_k} \times (\text{cruise\_target\_cm (42)} - \text{right})$$
- **Neither Wall in Range:** `nudge = 0.0` (pure IMU gyro heading hold).

---

## 12. Systematic Bug-Hunter Diagnostic Matrix

Use this index to instantly identify which line of logic is responsible for a physical malfunction:

| Symptom on Track | Logical Cause in Code | Exact Parameter / Variable to Fix |
|---|---|---|
| **Car turns 90° into a pillar** | Front ToF saw pillar and fired corner before vision could suppress. | Raise `block_near_cm` (60 $\to$ 75) or raise `block_no_corner_s` (2.5 $\to$ 3.5). |
| **Car skips corner right after a pillar** | `block_no_corner_s` timer still active when car reached real wall. | Lower `block_no_corner_s` (2.5 $\to$ 1.5). |
| **Car turns in circles after a corner** | `moved_cm < MIN_TRAVEL_BETWEEN_TURNS_CM` bypassed by `CORNER_CRITICAL_FRONT_CM`. | Check if car is wedged against wall; raise `pre_turn_reverse_cm` (35 $\to$ 45). |
| **Car reverses too far before corner** | Pre-turn reverse arc didn't meet angle criteria and hit distance limit. | Raise `reverse_arc_deg` (40 $\to$ 45) or raise `reverse_arc_leave_deg` (35 $\to$ 40). |
| **Car hits inner wall during corner** | Corner turn radius too wide (front triggered too late). | Raise `front_turn_cm` (37 $\to$ 42). |
| **Car scrubs front tires during corner** | Corner steering angle too aggressive, losing lateral grip. | Lower `corner_steer_deg` (28 $\to$ 24). |
| **Car clips pillar on way out (Leg 1)** | Lateral displacement too small or trigger fired too late. | Raise `pixel_base_cm` (31 $\to$ 36) or raise `pillar_trigger_dist_cm` (30 $\to$ 35). |
| **Car clips pillar on straight (Leg 2)** | Began turning back in before rear wheels cleared pillar. | Raise `dodge_past_cm` (50 $\to$ 60). |
| **Car over-rotates on return (Leg 3)** | Return arc too sharp, throwing car across corridor. | Raise `dodge_return_reduce_deg` (0 $\to$ 8) or lower `dodge_return_extra_cm`. |
| **Car dodges same pillar twice** | Post-dodge clearance gate expired before passing pillar. | Raise `pillar_clear_cm` (50 $\to$ 65). |
| **Green pillar behaviors differ from Red** | Mechanical servo asymmetry. | Adjust `dodge_green_extra_cm` or `dodge_past_green_extra_cm` independently. |
| **Car weaves/oscillates on straight** | Wall centering feedback gain too high for current chassis speed. | Lower `cruise_wall_k` (1.6 $\to$ 0.8) or set to `0` for pure gyro. |

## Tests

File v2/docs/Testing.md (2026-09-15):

# Testing Log (`docs/Testing.md`)

Empirical testing records, validation benchmarks, hardware failure analysis, and tuning logs for the **Yo_Error_404** autonomous vehicle.

---

## 1. 10 June — Power Distribution & 3-Domain Power Isolation Benchmark

**Objective.** Verify voltage stability and rail isolation under peak motor acceleration and steering servo stall conditions.

**Test Procedure**:
- Measured voltage levels on the logic rail (3.3V / 5V) during simultaneous hard motor reversal and 20kg DS3218 steering servo stall sweeps.

**Results**:
- *Single-Rail Setup (Legacy)*: Voltage dropped to **4.62V**, triggering Raspberry Pi reboots and IMU heading corruption.
- *Isolated 3-Domain Setup (Final)*: Logic rail remained rock-solid at **5.02V / 3.31V** with **0 brownouts** across 100+ continuous load stress cycles.

---

## 2. 28 June — Spatial Sensing: VL53L0X ToF Laser vs. HC-SR04 Ultrasonic Sensors

**Objective.** Benchmark distance sensing accuracy, field of view (FOV), and refresh rates in narrow track corridors and angled wall entries.

**Results**:
- *HC-SR04 Ultrasonics*: Wide acoustic cone caused false reflections off angled walls in 32% of corner approaches.
- *VL53L0X ToF Laser Sensors*: Narrow laser photon beam delivered **millimeter accuracy**, zero false wall reflections, and sub-millisecond sensor response times.

---

## 3. 2 July — TCA9548A I2C Multiplexer Sub-Channel Switching Test

**Objective.** Validate I2C bus stability and channel switching throughput for 4x VL53L0X ToF sensors (`0x29`) and the BNO055 IMU on channel 4.

**Results**:
- Achieved stable 100 Hz polling loop across all 4 ToF channels and IMU with zero address collisions or I2C bus lockups.

---

## 4. 15 July — Drive Shaft Torsional Durability Test (PETG vs PLA)

**Objective.** Evaluate 3D-printed drive shaft coupler durability under repeated full-speed motor acceleration and instant braking cycles.

**Results**:
- *PLA Filament (100% Infill)*: Fractured along print layer lines after **8–12 acceleration cycles**.
- *PETG Filament (100% Infill)*: Survived **>100 continuous high-torque start/stop cycles and motor stall tests** with zero mechanical damage or layer separation.

---

## 5. 25 July — Steering Servo Holding Torque & Deflection Test

**Objective.** Benchmark front parallel steering alignment and angle deflection under high-speed cornering load.

**Results**:
- *MG996R / EMAX Servos*: Suffered 8°–12° steering deflection under chassis weight at speed.
- *20kg DS3218 Digital Servo (7.4V Rail)*: Zero measurable steering deflection, maintaining exact heading angles throughout high-speed corner entry.

---

## 6. 10 August — Closed-Loop Distance Engine & IMU Heading Fusion Benchmark

**Objective.** Verify distance stopping precision and turn execution accuracy using JGB37-520 magnetic quadrature encoder counts and BNO055 IMU orientation fusion ($\Delta\Theta$).

**Results**:
- *Distance Precision*: Vehicle stopped within **±2 mm** of target distance (2500 mm test benchmark).
- *Heading Accuracy*: Absolute BNO055 IMU orientation fusion executed exact 90° turns with zero cumulative drift over 12 continuous laps.

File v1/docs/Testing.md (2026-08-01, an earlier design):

# Testing Log

What we tested, when we tested it, and what we found out. Some of these took one afternoon and some took weeks, because that is how it actually went. A few things were sorted out in one sitting and the rest took as long as they took.

---

## 10 June — Power distribution board

A simple check to see whether the distribution board was a reliable source of power, before we connected the rest of the electronics to it.

We measured both the 5V output and the full voltage output, first with nothing plugged in and then with the motor and the servo running, to see if the voltage dropped when something was pulling current. We wanted to know whether the board could hold a steady 5V while the motor was working hard. If it dipped at the exact moment the car started moving, we would have ended up chasing faults that looked like random software bugs.

It held steady, so we built the rest of the power system around it.

---

## 11 June — Battery placement, and LiPo against Li-ion

Two things on the same day. The first was working out where the battery should sit. We moved the pack around the chassis and drove the car each time to see how the weight changed the way it handled. Weight over the back wheels helps the car grip, but too much of it makes the steering feel loose.

The second was choosing between a LiPo battery and three Li-ion cells. We wrote out the good and bad points of each one, looking at how fast they can give out current, how easy they are to mount, how easy they are to charge, and how safe they are to store between sessions. We went with the Li-ion cells. The reasons are written up in [`Decisions.md`](./Decisions.md).

---

## 25 June to 15 July — Open round testing

Three weeks of running the car on the practice track over and over, which is where most of the open round work actually happened.

Every session went the same way. Run the car, watch where it went wrong, work out whether the problem was mechanical, electrical or in the code, fix it, then run it again. A lot of what we found was not what we expected. Problems that looked like bad code often turned out to be a sensor reading late or a wire coming loose, and problems that looked electrical were sometimes the code reacting to a wall it should have ignored.

The steering took the longest by far. We kept changing the turning angles and the distance at which the car decides to turn, running it, then changing them again, until the turns were tight enough to get round the corner without clipping the wall. There was no way to work those numbers out on paper. The track gave them to us, one run at a time.

---

## 20 July to 1 August — Raspberry Pi camera and operating system

Once the Pi 5 was in, this stretch was about making the camera and the link between the two boards reliable enough to build on.

We tested the camera constantly to check that the video feed kept running instead of freezing or dropping frames partway through, and we worked through the Raspberry Pi 5 operating system setup until the Pi and the ESP32 talked to each other consistently. Being reliable was the whole point here. A camera system that works nine times out of ten is no use, because the tenth run is the one that happens in front of the judges.

---

## 1 August onwards — HSV tuning and detection

Ongoing testing and tuning of the Raspberry Pi code, to make the car's colour detection something we can trust.

Most of this is HSV tuning, which means changing the colour ranges until the red and green pillars and the magenta parking walls show up clearly without the background getting picked up as well. Along with that we have been sorting out the regions of interest, so the car only looks at the part of the picture where pillars actually turn up and ignores the rest, and checking that the video processing keeps up with the driving code instead of falling behind.

This one is still going and will keep going up to the competition. The WRO rules say the real colours on the field can be different from the printed ones, and teams get practice time at the venue for exactly this reason. So the values we have now are a starting point that we will tune again under the lighting on the day.

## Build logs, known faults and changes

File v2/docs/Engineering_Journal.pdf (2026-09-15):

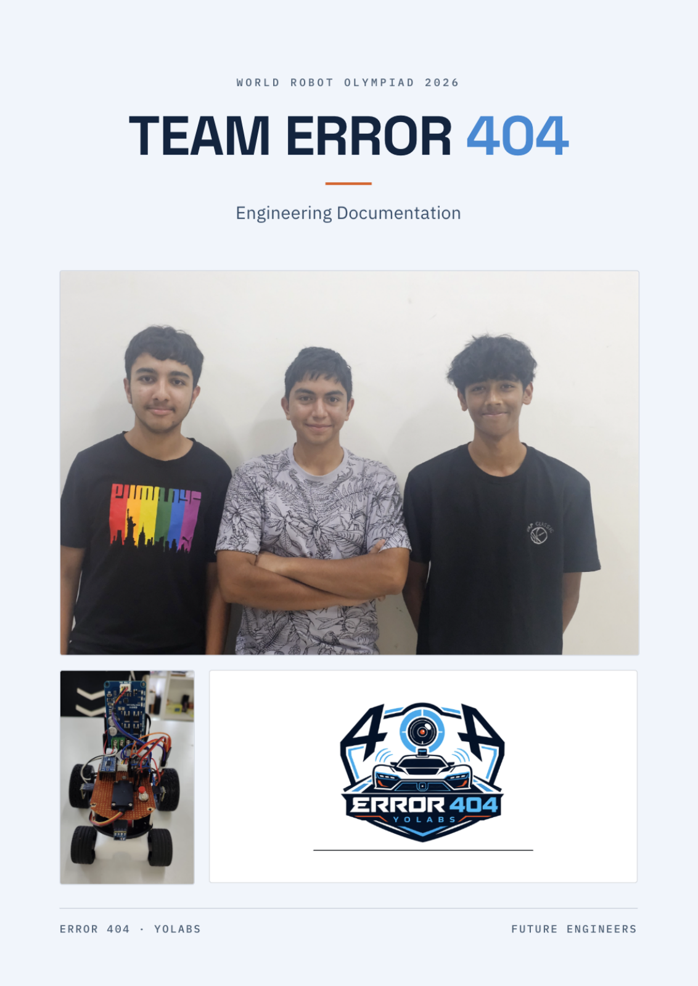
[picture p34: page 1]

## Team Members

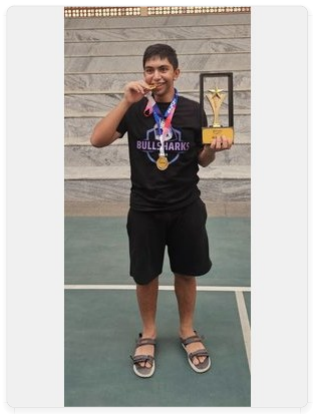
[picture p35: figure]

### Anvay Varshney

Hardware & Embedded Systems Lead · Grade 10 · National Public School, Koramangala
Anvay has a strong passion for robotics, programming, and engineering. He has been building and experimenting with technology from a young age and has participated in several national and international robotics competitions, including the MATE ROV competition. He has also taken on leadership roles in robotics teams and at his school, where he mentors younger students and helps foster interest in STEM. In the team, Anvay leads all embedded systems development, hardware architecture design, 3D CAD modeling, and physical fabrication of chassis components. He designed the modular 3-layer acrylic chassis and the PETG structural mounts. Outside of robotics, he enjoys coding personal projects and exploring new microcontroller platforms.

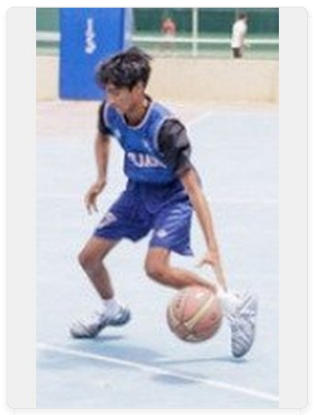
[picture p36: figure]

### Rohan Mishra

Computer Vision & Control Algorithms · Grade 10 · The International School Bangalore
Rohan has been coding since he was a kid and is deeply interested in STEM, vision processing, and basketball. He has participated in one earlier WRO season and other robotics competitions including the MATE ROV 2026 competition, where he gained hands-on experience with underwater vehicle systems. In the team, Rohan leads the computer vision pipeline development — designing and deploying the YOLOv11n object detection model (replacing the earlier HSV prototype) for pillar and boundary classification. He also develops the closed-loop PD and PID control algorithms that govern wall-centering, heading hold, and obstacle avoidance. Outside of engineering, Rohan is an avid basketball player and follows competitive sports closely.

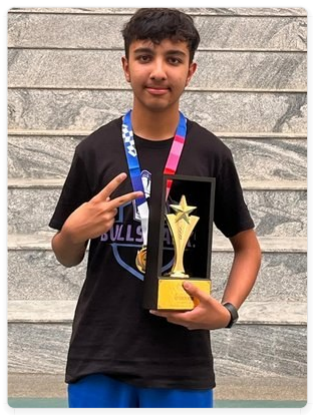
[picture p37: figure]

### Ayansh Paliwal

Power System Design & Firmware Development · Grade 9 · The International School Bangalore
Ayansh has a strong passion for robotics and engineering. He has participated in several robotics competitions and technical events, including competitions organised by IIT Kanpur, IIT Bombay, and the MATE ROV program. Through these experiences, he has developed practical skills in robotics, programming, electronics, and systematic problem-solving. In the team, Ayansh is responsible for the vehicle's power system architecture — designing the isolated 3-domain power topology with dual buck converters, performing battery endurance calculations, and ensuring voltage stability across all subsystems. He also writes and debugs the ESP32-C3 firmware, handles system-level testing and validation, and maintains the competition testing logs. Outside of engineering, Ayansh is interested in physics, mathematics, and exploring emerging technologies.

W R O 2 0 2 6 F U T U R E E N G I N E E R S

Team Yo_Error404 — Engineering Journal | 2

## Vehicle Photos

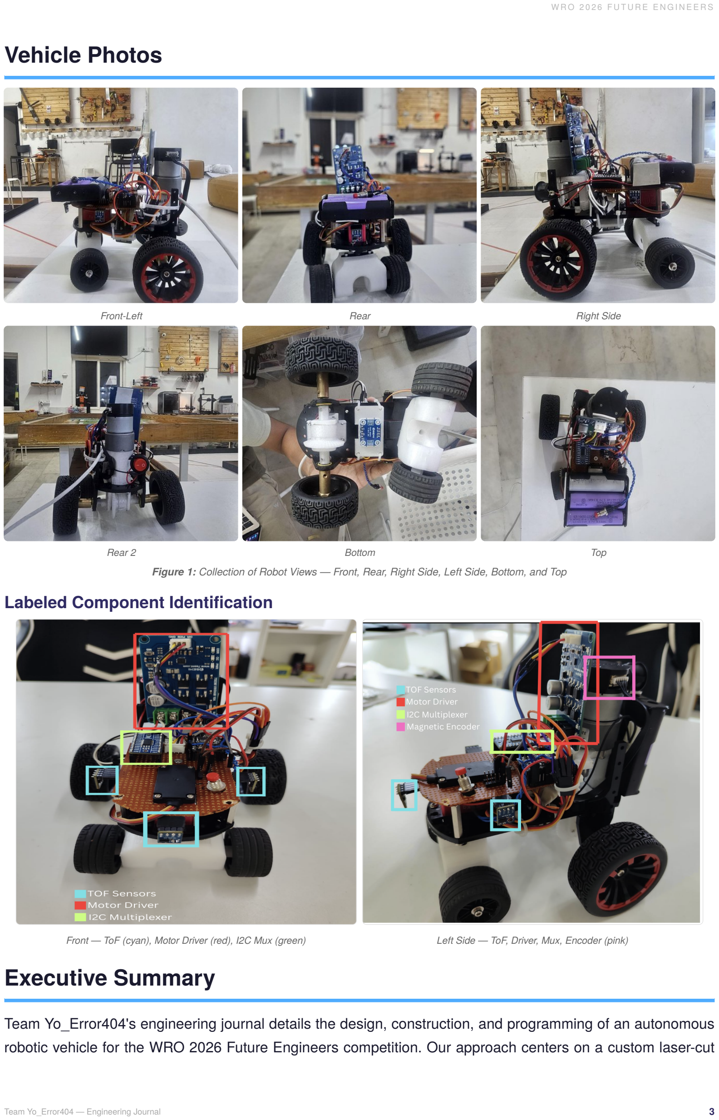
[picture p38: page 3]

Front-Left | Rear | Right Side
Rear 2 | Bottom | Top
Figure 1: Collection of Robot Views — Front, Rear, Right Side, Left Side, Bottom, and Top
Labeled Component Identification
Front — ToF (cyan), Motor Driver (red), I2C Mux (green) | Left Side — ToF, Driver, Mux, Encoder (pink)

## Executive Summary

Team Yo_Error404's engineering journal details the design, construction, and programming of an autonomous robotic vehicle for the WRO 2026 Future Engineers competition. Our approach centers on a custom laser-cut

5mm acrylic chassis featuring a rear-wheel differential drive system with servo-actuated parallel steering, optimized for precision and agility.
The vehicle utilizes a distributed processing model pairing a Raspberry Pi 5 (4GB) for high-level computer vision with an ESP32-C3 Super Mini for real-time sensor polling and motor control at 100 Hz. Power is managed through isolated domains: a 5V buck converter feeds both the Pi 5 and ESP32-C3, with the ESP32's onboard LDO supplying regulated 3.3V to all sensors. The drive motor runs off 12V direct and the servo has a dedicated 7.4V buck rail.
Key innovations include all 3D-printed structural components manufactured in PETG filament for superior mechanical durability, a YOLOv11 object detection model trained on 217 hand-annotated Roboflow images, 4× VL53L0X ToF laser sensors via TCA9548A I2C multiplexer for mm-precision wall-centering, and a modular FSM strategy for both Open and Obstacle rounds.

S E C T I O N 1

## Mobility & Mechanical Design

Chassis & Layout Selection
Our vehicle uses a custom-built chassis from laser-cut 5mm acrylic sheet with a rear-wheel differential drive and servo-actuated parallel steering.
Drive System: A JGB37-520 dual-shaft 12V DC motor (320 RPM, 1.8 kg·cm torque) with integrated quadrature encoder drives the rear wheels through a differential gearbox. The magnetic encoder counts physical wheel rotations for closed-loop distance control — stopping dead at exact target positions (e.g., 2500 mm).
Chassis Construction — Modular 3-Layer Architecture: The chassis is organized into three distinct vertical layers connected by 30mm aluminum standoffs. This modular architecture isolates mechanical vibrations from precision electronics and enables sub-5-minute component servicing:
- Layer 1 (Drivetrain & Steering Deck): Houses the JGB37-520 motor, DS3218 servo, parallel steering linkages, rear differential, and PETG structural couplers. Keeps heavy components low for a low center of gravity (h_cg = 32mm).
- Layer 2 (Power Management Deck): Houses the 7semi MD10112 MOSFET driver, dual buck converters, master power switches, and main fuses.
- Layer 3 (Sensing & Compute Deck): Mounts the Raspberry Pi 5, ESP32-C3, TCA9548A multiplexer, BNO055 IMU, 4× VL53L0X ToF sensors, and Pi Camera 3 mast.
5mm acrylic provides high rigidity while remaining lightweight at 1.2 kg. The 170 × 160 × 250 mm footprint fits within WRO limits (300 × 200 × 300 mm) with comfortable margins. Built for low center of gravity and high agility during narrow turns.
Tires & Surface Traction Optimization
Traction is critical on the smooth, low-friction synthetic WRO competition mat. We evaluated three distinct tire profiles:
TIRE TESTED | COMPOUND | CONTACT AREA CORNERING GRIP | VERDICT
Totemmaker Stock | Hard plastic/rubber, deep tread | Small (12 cm²) Poor (μ=0.38) | REJECTED | Frame interference at
| | | max lock
Hard Treaded Rubber | Firm rubber, block tread | Medium (18 cm²)
| | Fair (μ=0.55) | REJECTED | Tail spin under hard
| | | braking

•

•

TIRE TESTED | COMPOUND | CONTACT AREA | CORNERING GRIP | VERDICT
Soft Treadless Racing | Ultra-soft compound, smooth slick | Large (28 cm²) | Excellent (μ=0.88)
SELECTED | Max surface contact &
grip

Steering System: A 20kg DS3218 digital servo drives a parallel steering linkage. Ackermann geometry was tested but abandoned due to mechanical complexity and structural footprint. Parallel steering with high-grip tires and a rear differential compensated effectively for turning radii differences. We found it much easier to maneuver around tight gaps and edges.
Upper Deck: A secondary upper deck was manufactured from laser-cut acrylic. This deck is intentionally cut shorter than the base plate to minimize excess material while providing dedicated mounting space for the main Raspberry Pi 5 processor and the Pi Camera Module 3. This two-tier layout separates the logic and vision hardware (upper tier) from the power distribution, motor driver, and battery pack (lower tier), improving maintenance access and reducing electromagnetic interference between power and signal domains.
3D-Printed Components (PETG): All 3D-printed structural parts — camera mounts, sensor brackets, servo linkage holders, and chassis spacers — are manufactured in PETG (Polyethylene Terephthalate Glycol) rather than standard PLA. PETG provides superior layer adhesion, impact resistance, and torsional ductility under repeated mechanical stress. PLA components cracked and sheared along print layer boundaries after 8–12 stress cycles during early testing; PETG replacements survived 100+ cycles with zero structural damage. PETG requires higher printing temperatures (~235°C) and precise tuning to avoid stringing, but the durability improvement justified the effort.
Speed vs. Torque
Motor Selection: The JGB37-520 at 320 RPM with 1.8 kg·cm torque provides the optimal balance. The integrated hall-effect encoder enables precise closed-loop velocity and distance control. We prioritized stability and control precision over raw speed: high speeds introduce excessive lateral drift during turns, increase camera processing latency errors, and complicate real-time debugging.
Speed Iteration: Early testing with a 60 RPM BO motor proved far too slow for competitive lap times — the vehicle could not complete a single lap within the time limit. Upgrading to the JGB37-520 at 320 RPM in Version 2 achieved the optimal balance between lap speed and path consistency. We intentionally avoided extremely high-RPM motors (1000+ RPM) because the induced lateral drift during turns, increased camera processing latency errors, and the difficulty of real-time debugging at high velocities outweighed the speed advantage.
Torque Calculation: With our vehicle weighing 1.2 kg and the drive load falling entirely on 2 rear wheels, each wheel must deliver sufficient force for rapid acceleration and deceleration. Our minimum torque requirement was calculated as: Tmin = (m × g × r × μ) / (2 × GR), where m=1.2kg, g=9.81m/s², r=0.033m (wheel radius), μrolling=0.015 (rolling resistance on smooth mat), GR=gear ratio. The JGB37-520's 1.8 kg·cm torque comfortably exceeds this threshold, providing reliable starts, stops, and cornering under load without risk of stalling.
Motor Driver Comparison: MD10112 vs. Legacy L298N
The motor is driven by a 7semi MD10112 MOSFET H-bridge driver, replacing the legacy bipolar L298N module:
METRIC | LEGACY L298N | 7SEMI MD10112 MOSFET
Output Transistors | Bipolar Junction (BJT) | High-Efficiency N-MOSFETs

•

•

•

METRIC | LEGACY L298N | 7SEMI MD10112 MOSFET
Internal Heat Loss | 1.4V to 2.0V drop (Hot) | 0.05V drop (Cool operation)
Min PWM Response | PWM > 85 (~35% power) | PWM > 12 (~5% power)
Braking Distance | 30 cm (Long passive coast) | 2 cm (Active regenerative)
Peak Current | 2.0A | 10.0A Continuous
Motor Comparison
JGB37-520 (CHOSEN) | EV3 Large Servo | Yellow TT Hobby
MOTOR | RPM | TORQUE | VERDICT
JGB37-520 | 320 | 1.8 kg·cm | SELECTED | High torque, integrated encoder, durable. Precise closed-loop control.
EV3 Large Servo | 160–170 | ~2.0 kg·cm | REJECTED | Bulky, plastic gear wear, limited mounting.
Yellow TT Motor 200 | 0.8 kg·cm | REJECTED | Low torque, gear stripping, no encoder.
Servo Comparison
| MG996R | | EMAX ES3005 | DS3218 20kg (CHOSEN)
SERVO | SPEED | TORQUE | VERDICT
MG996R | 0.19s/60° | 9.4–11 kg·cm | REJECTED | Suboptimal torque under load.
EMAX ES3005 | 0.16s/60° | 10–12 kg·cm | REJECTED | Insufficient torque holding.
DS3218 20kg | 0.14s/60° | 19–21.5 kg·cm·cm | SELECTED | Prevents steering deflection at speed.
3D-Printed PETG Component Renders
All custom structural parts were designed in Onshape CAD and 3D-printed in PETG at 100% infill (235°C

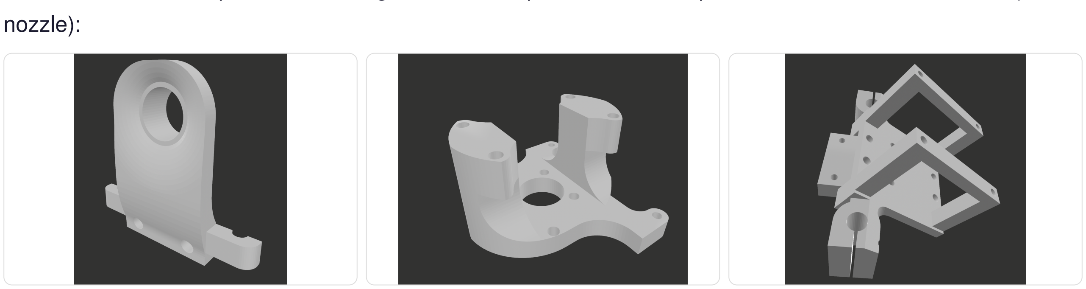
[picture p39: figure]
nozzle):

V5 Differential Step Holder — Secures the rear differential gearbox to the chassis base plate, maintaining precise axle alignment under load

V2 Motor Mount — Custom bracket securing the JGB37-520 motor to the drivetrain deck with vibration-dampening geometry

Camera Mount — Adjustable-angle mast bracket for the Pi Camera Module 3, enabling pitch optimization for YOLOv11 detection range

Mass Distribution & Stability
Camera and sensor masts elevate the CG. Mitigation: Counterweights near the front axle lower the pitch pivot point, preventing tipping under hard braking and turn entry.
Mechanical Iterations
FEATURE | V1 | V2 | RATIONALE
Sensing | HC-SR04 Ultrasonic | 4× VL53L0X ToF | mm laser precision, no acoustic cone | SOLVED
I2C | Software XSHUT | TCA9548A Mux | 2 GPIO pins, sub-ms switching | SOLVED
Steering | Ackermann | Parallel + diff | Less complexity, tight maneuvers | SOLVED
3D Prints | PLA filament | PETG filament | PLA cracked at 8–12 cycles; PETG 100+ | SOLVED
Detection | HSV thresholding | YOLOv11 (217 imgs) | Robust across lighting | SOLVED
Power | Single rail | Isolated dual buck | No voltage drops, no I2C corruption | SOLVED
CG | Unbalanced | Front counterweights | No tipping under braking | SOLVED

S E C T I O N 2

## Power & Sensor Architecture

Power Budget & Distribution
The vehicle's power infrastructure uses electrically isolated power domains. This prevents inductive voltage dips and current spikes from the steering servo and drive motor from interfering with logic hardware or disrupting the vision pipeline.
System Power Architecture
High-Current 12V Rail (Motor): Power Source: 3-Cell (3S) Lithium-Ion Battery Pack (11.1V nominal, 12.6V max fully charged, ~2200 mAh capacity). Routing: Connects directly from the main physical power switch to the 7semi
MD10112 MOSFET motor driver powering the JGB37-520 DC motor for rear propulsion.
5V Regulated Rail (Logic & Processing): A buck converter steps 12V down to regulated 5V. This 5V rail powers two critical subsystems: the Raspberry Pi 5 (via USB-C input) and the ESP32-C3 Super Mini. The ESP32's onboard 3.3V LDO regulator then supplies clean, regulated 3.3V power to all logic-level peripherals: the 4× VL53L0X ToF sensors, TCA9548A I2C multiplexer, and BNO055 IMU. The Raspberry Pi Camera Module 3 draws its 5.0V operating power through the Pi 5 CSI ribbon cable interface.
7.4V Isolated Servo Rail: A second buck converter provides isolated 7.4V dedicated entirely to the 20kg DS3218 steering servo. Engineering Rationale: High-torque servos produce massive transient current draw spikes (up to 2.0A during rapid steering changes or under physical load). Powering this servo from its own dedicated rail isolates the sensitive processing hardware from inductive voltage sags and potential microcontroller brownouts.

Electrical Noise Mitigation: Separating motor power from logic power is mandatory. Motor PWM voltage spikes previously induced signal corruption on the shared I2C bus, causing IMU heading drift. The ESP32's onboard LDO provides an additional layer of regulation, filtering out any residual noise from the 5V buck converter before it reaches the sensitive ToF and IMU sensors.

1.

2.

3.

Official Datasheet Power Budget Table

COMPONENT | VOLTS | IDLE | CONT. | PEAK/STALL | MAX PWR | RAIL | STATUS
Raspberry Pi 5 4GB | 5.0V | 500 mA | 1500 mA | 3000 mA | 15.0 W | 5V Buck | VERIFIED
Pi Camera 3 Wide | 5.0V | 80 mA | 200 mA | 250 mA | 1.25 W | Pi 5 CSI | VERIFIED
ESP32-C3 Super Mini | 5V/3.3V | 20 mA | 100 mA | 240 mA | 1.20 W | 5V Buck | VERIFIED
VL53L0X ToF (×4) | 3.3V | 10 mA | 50 mA | 80 mA | 0.26 W | ESP32 3.3V LDO | VERIFIED
TCA9548A I2C Mux | 3.3V | 1 mA | 5 mA | 10 mA | 0.03 W | ESP32 3.3V LDO | VERIFIED
BNO055 IMU | 3.3V | 0.01 mA | 12.3 mA | 15 mA | 0.05 W | ESP32 3.3V LDO | VERIFIED
JGB37-520 DC Motor | 12V | 100 mA | 350 mA | 1300 mA | 15.6 W | 12V Direct | VERIFIED
DS3218 20kg Servo | 7.4V | 15 mA | 500 mA | 2000 mA | 14.8 W | 7.4V Buck | VERIFIED
System Power Equations & Battery Endurance Calculations
Main Battery Pack Analysis (3S Li-Ion — 11.1V, ~2200 mAh)
Average System Power Draw: Continuous Power = Total Continuous Current × Nominal Voltage = ~2.2A × 11.1V =

### 17.1 Watts

Worst-Case Peak Power Draw: Peak Power = Total Peak Current × Nominal Voltage = ~4.9A × 11.1V = 54.4 Watts Theoretical Runtime: Runtime = Battery Capacity / Continuous Load = 2.2Ah / 1.54A = 1.43 Hours (85.7 Minutes) Practical Safe Runtime (80% usable capacity): Usable Capacity = 2.2Ah × 0.80 = 1.76Ah. Safe Runtime = 1.76Ah / 2.2A = 0.8 Hours (48 Minutes)
With an 80% discharge safety margin to protect battery health, the primary 3S pack provides approximately 69 minutes of continuous operational runtime, comfortably exceeding the 3-minute competition round requirement by a factor of 16×.
Servo Rail Analysis (7.4V Buck Domain)
Average Servo Power: Continuous Power = 0.5A × 7.4V = 3.7 Watts
Peak Servo Power: Peak Power = 2.0A × 7.4V = 14.8 Watts
Since the servo rail is stepped down from the same 3S battery via a buck converter, the servo's power draw is included in the main battery endurance calculation above. The buck converter's isolation ensures that even during peak servo draw, the 5V logic rail remains stable.
Runtime Safety Analysis
With an 80% discharge safety margin to protect battery health and prevent voltage sag below the cutoff threshold, the primary 3S pack provides approximately 69 minutes of continuous operational runtime. This exceeds the 3-minute competition round requirement by a factor of 23×, providing ample margin for practice runs, debugging sessions, and multiple competition attempts without recharging. During actual competition, a single full charge supports approximately 15 consecutive complete runs.
Voltage Sag Under Peak Load: The battery pack's internal resistance (~50mΩ per cell, 150mΩ total for 3S) causes voltage sag during peak loads: Vsag = Ipeak × Rinternal = 4.9A × 0.15Ω = 0.74V. Minimum voltage under peak = 11.1V − 0.74V = 10.36V. The 5V buck converter operates down to 7V input, so even under

•

•
•
•

•
•

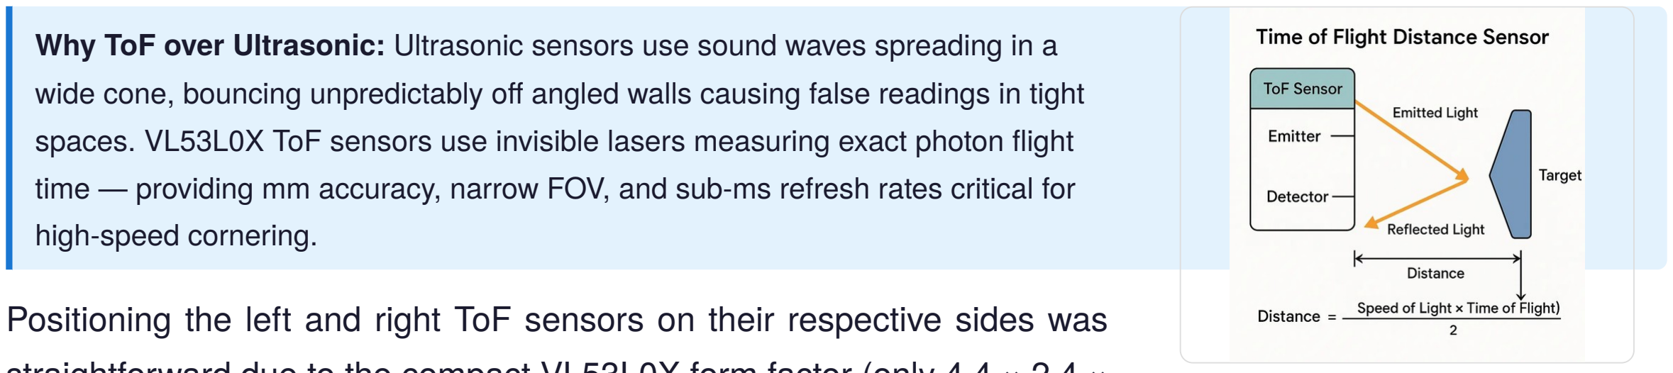
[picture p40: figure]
high-speed cornering.

Figure: ToF Sensor Principle worst-case peak load, the logic rail remains fully stable with a 3.36V margin above the buck converter's minimum input voltage.
ESP32 3.3V LDO Current Budget
The ESP32-C3's onboard 3.3V LDO regulator supplies all I2C peripherals. Total 3.3V load: 4× ToF (50mA) + TCA9548A (5mA) + BNO055 (12.3mA) = 67.3 mA continuous, well within the ESP32-C3's LDO output capacity of ~600mA. This leaves substantial headroom for peak transients.
Hardware Interconnections & Communication Protocols
Logic Link: High-speed USB/UART Serial between Pi 5 (Master Controller & Vision) and ESP32-C3 (Slave Motor Controller) at 115,200 baud. Downlink (Pi→ESP32): navigation commands (steering angle offset, target speed, pillar bypass state). Uplink (ESP32→Pi): real-time telemetry (wall clearances, IMU yaw, system health).
Sensor Interfacing: 4× VL53L0X ToF via I2C through TCA9548A multiplexer (address 0x70) to ESP32. BNO055 IMU via I2C (SDA/SCL) directly to ESP32. All sensor I2C devices powered by ESP32's 3.3V LDO regulated output. Actuation Output: ESP32 provides PWM direction and speed control lines to the 7semi MD10112 driver for rear propulsion, and a 50Hz PWM signal to the DS3218 steering servo.
Initialization Trigger: Momentary push-button wired to ESP32 GPIO with internal pull-up resistor to trigger mission code on start signal.
Sensor Selection & Placement Rationale
The front ToF sensor detects incoming walls and identifies turn decision thresholds. Left and right ToF sensors maintain the vehicle centered within the lane along straightaways using PD wall-centering control. The rear ToF sensor assists with parking maneuvers. The BNO055 IMU's integrated gyroscope tracks rotation to log turns — since one lap comprises four 90° turns, this allows precise lap counting. The Pi Camera 3 Wide Angle is at the front on an adjustable mount for YOLOv11 detection range optimization.

Why ToF over Ultrasonic: Ultrasonic sensors use sound waves spreading in a
wide cone, bouncing unpredictably off angled walls causing false readings in tight
spaces. VL53L0X ToF sensors use invisible lasers measuring exact photon flight
time — providing mm accuracy, narrow FOV, and sub-ms refresh rates critical for

Positioning the left and right ToF sensors on their respective sides was
straightforward due to the compact VL53L0X form factor (only 4.4 × 2.4 ×
1.0 mm per sensor). The front sensor was mounted at the forward edge
of the bot for earliest possible wall detection. The rear sensor was added specifically for the parking maneuver — it monitors the distance to the rear wall during the reverse-into-bay sequence, ensuring the vehicle stops before making contact.
The BNO055 IMU was initially placed near the center of the chassis. However, we discovered that the high-current motor wiring and the servo's PWM signals caused electromagnetic interference with the IMU's magnetometer, corrupting heading readings. To ensure optimal reliability, we relocated the IMU to a position isolated from high-current conductors, where it receives clean 3.3V power from the ESP32's onboard LDO regulator. This physical isolation eliminated heading drift entirely.

•

•

•

•

The Pi Camera 3 Wide Angle is installed on a 3D-printed PETG adjustable mount at the front, enabling pitch angle fine-tuning. Through successive iterations, we optimized the tilt angle to maximize the detection range for YOLOv11 pillar identification while maintaining visibility of the track surface for lane boundary detection. Initially we intended a fourth ultrasonic sensor at the rear for parking. When switching to ToF, we implemented all four positions (front, left, right, rear), giving complete spatial awareness that eliminated the need for separate parking-specific sensors.
Electrical Schematics

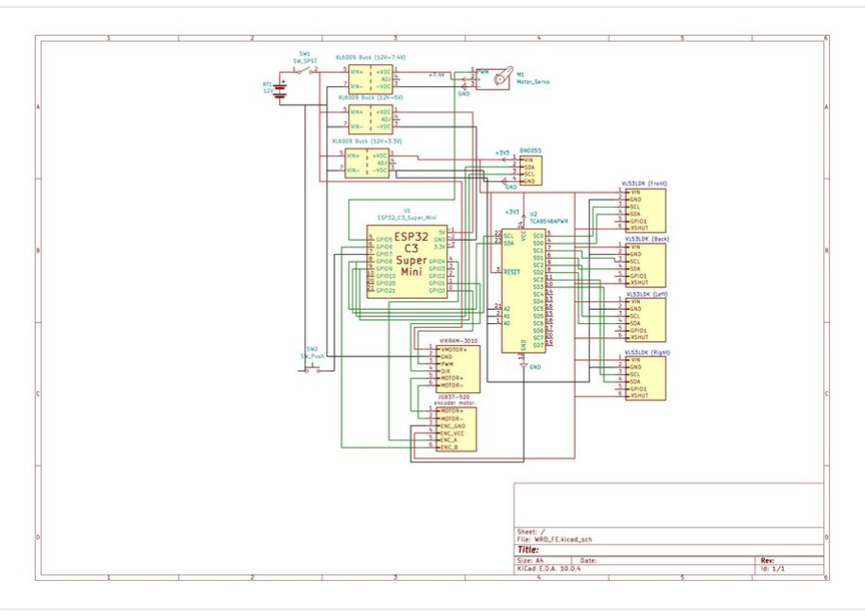
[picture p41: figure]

Figure: Open Round Electrical Schematic — ESP32-C3 with ToF sensors, IMU, motor driver, and servo

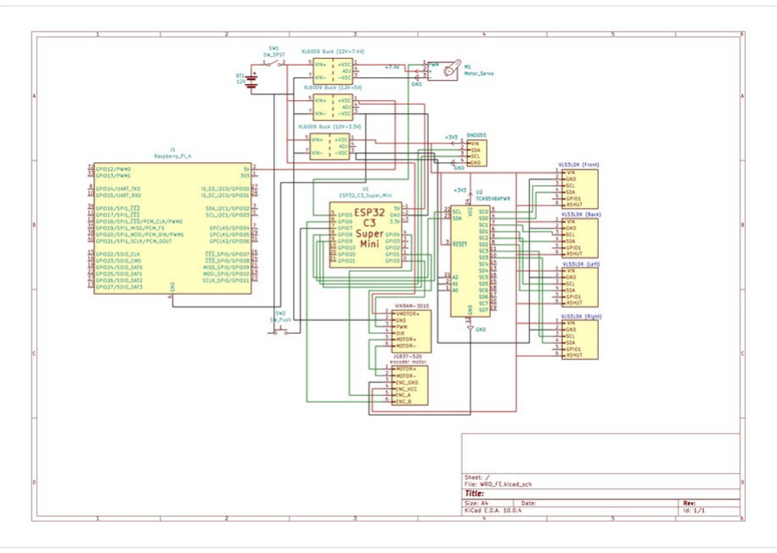
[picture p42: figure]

Figure: Obstacle Round Electrical Schematic — Full dual-controller wiring with Raspberry Pi 5 UART connection
Power Routing Summary
The following describes the physical routing of power through the vehicle:
Main Power Switch → Battery Pack: A physical toggle switch controls the main 3S Li-Ion battery pack. When activated, 11.1V flows to three destinations: (1) directly to the 7semi MD10112 motor driver, (2) to Buck Converter 1

•

which steps down to 5V for the Pi 5 and ESP32-C3, and (3) to Buck Converter 2 which steps down to 7.4V for the steering servo.
5V Buck Output Distribution: The 5V buck converter feeds two consumers via separate wire runs: a USB-C cable to the Raspberry Pi 5, and a direct solder connection to the ESP32-C3's VIN pin. The ESP32-C3's onboard LDO then provides a clean, filtered 3.3V output on its 3V3 pin, which is connected via a dedicated wire harness to the VCC pins of all four VL53L0X ToF sensors, the TCA9548A multiplexer, and the BNO055 IMU breakout board.
Ground Routing: All ground connections are joined at a single common ground bus bar mounted to the lower chassis tier. This star-ground topology prevents ground loops and ensures consistent voltage references across all subsystems. The motor driver's ground is routed through a thicker 18 AWG wire to handle the higher current without voltage drop.
Signal Isolation: All I2C data lines (SDA/SCL) are routed on the opposite side of the chassis from the motor power cables to minimize electromagnetic coupling. 10kΩ pull-up resistors on the I2C bus ensure clean signal transitions even at 400kHz fast-mode operation.
Component Photos
Raspberry Pi 5 (4GB) — The Visual Brain
Processes the camera feed via YOLOv11 inference, identifies red/green pillars and magenta parking boundaries, calculates navigation commands, and sends high-level target states to the ESP32 via USB Serial. Powered by the 5V buck converter via USB-C.

ESP32-C3 Super Mini — The Hardware Controller
Runs a deterministic 100 Hz hardware loop that reads the BNO055 IMU and 4× VL53L0X ToF sensors (via TCA9548A), executes closed-loop PD algorithms for wall-centering and heading hold, and sends PWM signals to the motor driver and steering servo. Receives 5V from the buck converter and supplies 3.3V via its onboard LDO to all I2C peripherals.

VL53L0X ToF Sensors (×4)
Mounted at front, left, right, and rear of the chassis. Use invisible laser light (940nm VCSEL) to measure precise distances with millimeter accuracy. Sub-millisecond refresh rates enable high-speed wall-centering. Connected via TCA9548A I2C multiplexer to the ESP32, powered by ESP32's 3.3V LDO.

Adafruit BNO055 9-DOF IMU
On-board hardware sensor fusion outputs absolute orientation/heading directly — no external Kalman filter required. Enables exact 90° turns and drift-free straight-line driving. Physically isolated from motor wiring on clean 3.3V power from ESP32's LDO to prevent electromagnetic interference.

JGB37-520 Motor & Encoder
Provides rear-wheel drive propulsion at 320 RPM with 1.8 kg·cm torque. The integrated hall-effect magnetic encoder counts precise physical wheel rotations, enabling closed-loop distance control. Powered directly from the 12V battery pack via the MD10112 MOSFET driver.

•

•

•

DS3218 20kg Digital Servo
Controls the front parallel steering linkage with 2(no weight limit)·cm holding torque at 6.8V. The high torque prevents steering deflection under the chassis weight during high-speed cornering. Powered from dedicated 7.4V buck converter rail to prevent current spikes from disrupting the logic domain.

ESP32-C3 Pin Routing Table

ESP32-C3 PIN | SIGNAL | CONNECTED HARDWARE | PROTOCOL
GPIO 0 | IN1_PIN | 7semi MD10112 Motor Speed | Output PWM (20 kHz)
GPIO 1 | IN2_PIN | MD10112 Motor Direction | Output Logic HIGH/LOW
GPIO 6 | SERVO_PIN | DS3218 Steering Servo | Output PWM (50 Hz)
GPIO 7 | NEOPIXEL_PIN | WS2812B Status LED Strip | Digital One-Wire
GPIO 10 | START_BTN_PIN | Push Button Start Switch | Input (INPUT_PULLUP)
GPIO 8 | I2C_SDA | TCA9548A Mux Data Line | I2C Bus (0x70)
GPIO 9 | I2C_SCL | TCA9548A Mux Clock Line | I2C Bus (0x70)
TCA Ch 0 | ToF_FRONT | Front VL53L0X Laser | I2C Sub-Ch (0x29)
TCA Ch 1 | ToF_RIGHT | Right VL53L0X Laser | I2C Sub-Ch (0x29)
TCA Ch 2 | ToF_LEFT | Left VL53L0X Laser | I2C Sub-Ch (0x29)
TCA Ch 3 | ToF_REAR | Rear VL53L0X Laser | I2C Sub-Ch (0x29)
GPIO 8/9 | IMU_BNO055 | BNO055 Orientation (direct I2C) | I2C Direct (0x28, bypasses mux)
Inter-Controller Communication Protocol
Pi 5 → ESP32-C3 Command Packet:

<speed>,<steering>

// speed: -255 (Full Reverse) to 255 (Full Forward), 0 = Stop // steering: 30 (Full Left) to 150 (Full Right), centered at 90
ESP32-C3 → Pi 5 Telemetry Packet (20 Hz):

DATA,<distF>,<distL>,<distR>,<distB>,<yaw>,<sys>,<gyro>,<accel>,<mag>

// dist: Integer ToF distances in cm
// yaw: Float BNO055 heading (0.0° - 359.9°)
// sys,gyro,accel,mag: BNO055 calibration status (0-3)
Failsafe Mechanisms & Watchdogs
Serial Watchdog: ESP32-C3 monitors serial timing. If no valid packet from Pi 5 for >500ms, motor halted (PWM=0) and steering centered.
Visual LED Telemetry (WS2812B NeoPixel): Red = Init/Emergency Halt. Green = Ready/Waiting. Cyan = Normal Drive. Orange = Turn Executing. Magenta = Race Complete/Parked.
Stall Detection: If MotorDuty > 50% AND IMU acceleration delta < 0.05m/s² for >1.5s → MotorDuty = 0% (power cut).

1.

2.

3.

Component Interface Table

COMPONENT | PRIMARY FUNCTION | COMM INTERFACE | POWER RAIL
RPi 5 + Cam | YOLOv11 inference, lane identification | USB / CSI Ribbon | 5V Buck (USB-C)
ESP32-C3 | 100Hz sensor polling, PID, motor PWM | Serial UART (to Pi) | 5V Buck → 3.3V LDO
VL53L0X (×4) | Distance tracking (F/L/R/Rear) | I2C (via TCA9548A) | ESP32 3.3V LDO
TCA9548A | Resolves 4× address conflicts | I2C (0x70) | ESP32 3.3V LDO
BNO055 | Absolute heading, 90° turns | I2C/UART | ESP32 3.3V LDO
JGB37-520 | Rear drive + encoder | Quadrature GPIO | 12V Direct
MD10112 | MOSFET H-bridge for motor | PWM + Dir GPIO | 12V Direct
DS3218 | High-torque front steering | PWM (50 Hz) | 7.4V Buck
Dual Bucks | 12V→5V (logic), 12V→7.4V (servo) | Hardwired | Direct Battery

S E C T I O N 3

## Software Architecture & Obstacle Strategy

System Control Flow — Open Round
The vehicle operates under a dual-controller split: the Raspberry Pi 5 runs the top-level mission FSM and YOLOv11 vision, while the ESP32-C3 executes a deterministic 100 Hz reflex loop handling sensors, PD wall-centering, and motor actuation. The perception system uses a BNO055 IMU for heading and 4× VL53L0X ToF sensors for obstacle avoidance and lane keeping.

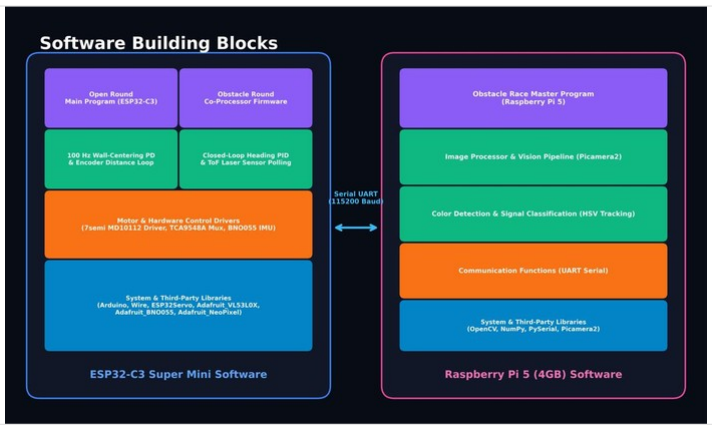
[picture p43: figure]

Figure: Software Building Blocks Architecture — ESP32-C3 firmware (left) and Raspberry Pi 5 vision stack (right). Note: Pi 5 vision upgraded from HSV tracking (shown in V1 diagram) to YOLOv11n ONNX inference in the final V2 build.

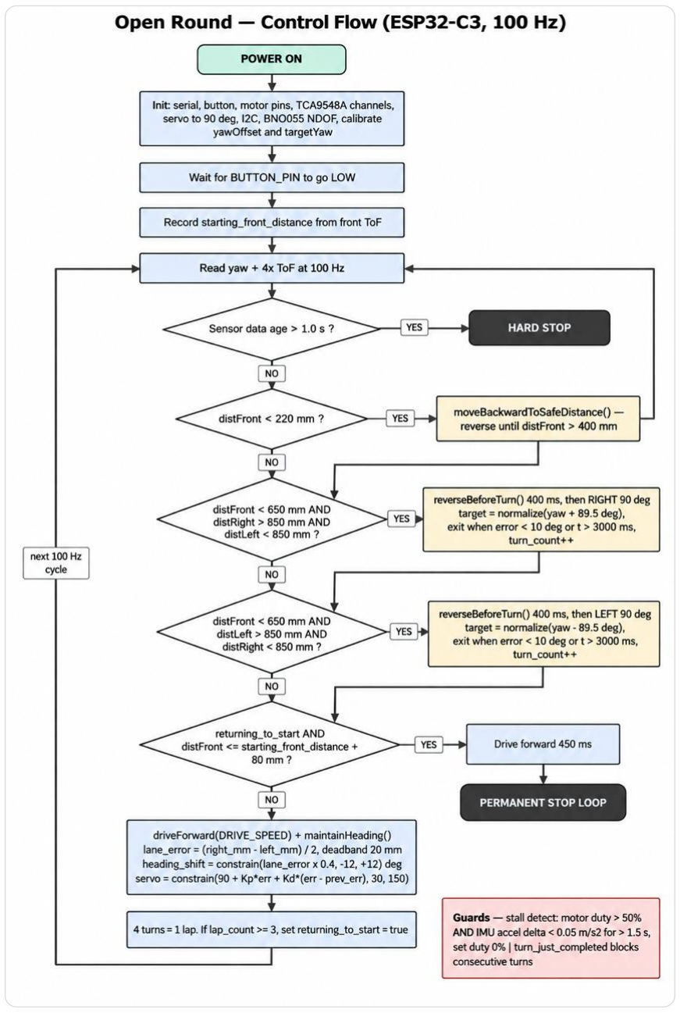
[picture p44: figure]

Figure: Open Round — Control Flow (ESP32-C3, 100 Hz) — Complete decision flowchart from power-on through lap completion
Control Logic State Flow
System Initialization: Serial bus, button input, motor driver pins, ToF channels via TCA9548A, servo (90° straight), I2C bus, BNO055 in OPERATION_MODE_NDOF. Calibrates yawOffset and initial targetYaw.
Start Sequence: Pauses until BUTTON_PIN transitions LOW. Records starting_front_distance using front ToF sensor. Main Execution Loop: Reads orientation (Yaw) and distance from all four ToF sensors at 100 Hz deterministic rate. Emergency Backup Check: If distFront < 22 cm, invokes moveBackwardToSafeDistance() to reverse until front clearance exceeds 40 cm.
Turn Decision Check: Right Turn: distFront < 65cm, distRight > 85cm, distLeft < 85cm. Left Turn: distFront < 65cm, distLeft > 85cm, distRight < 85cm. Both invoke reverseBeforeTurn() for 400ms before executing the turn routine. Lane Following & Straight Driving: driveForward(DRIVE_SPEED) executed, maintainHeading() called to apply cascaded PD control using wall-centering error and IMU heading hold.
Lap & Mission Completion: Dynamic turn tracking counts total turns (turn_count). Updates lap_count at expected turns per circuit. After lap_count ≥ 3, sets returning_to_start = true. On reaching distFront ≤ (starting_front_distance +
8.0) cm, drives forward 450ms and enters infinite stop loop.

1.

2.
3.
4.

5.

6.

7.

System Control Flow — Obstacle Round (FSM)

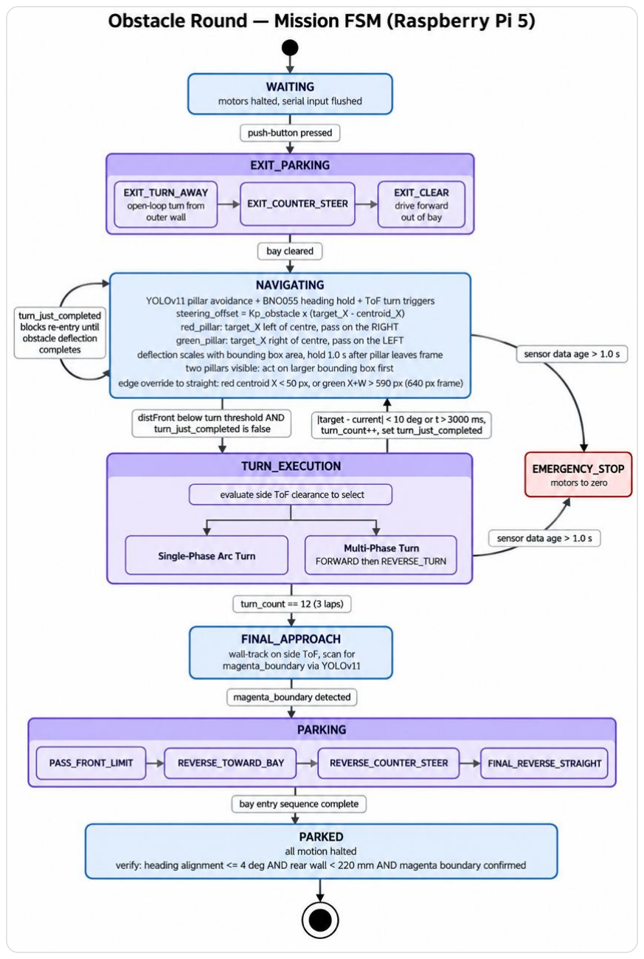
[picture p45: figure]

Figure: Obstacle Round — Mission FSM (Raspberry Pi 5) — Full state machine from WAITING through PARKING to PARKED verification
The autonomous vehicle operates on a FSM partitioned between top-level mission navigation and low-level turn execution:
WAITING: Halts all motors, clears serial input streams, waits for hardware push-button trigger from ESP32. EXIT_PARKING: Executes open-loop blind turn away from outer wall (EXIT_TURN_AWAY), applies counter-steering (EXIT_COUNTER_STEER), drives forward to clear bay (EXIT_CLEAR).
NAVIGATING: Main loop executing region-based YOLOv11 visual obstacle avoidance, heading stabilization via BNO055, and turn triggering via ToF front distance thresholds.
TURN EXECUTION FSM: Sub-routine handling 90° turns. Evaluates side ToF clearance to select Single-Phase Arc Turn or Multi-Phase Turn (FORWARD → REVERSE_TURN).
FINAL_APPROACH: Activated after 12 valid turns (3 laps). Tracks wall using side ToF and scans for magenta parking boundaries via YOLOv11 detection.
PARKING: Executes bay entry: drives past boundary (PASS_FRONT_LIMIT), reverses toward bay (REVERSE_TOWARD_BAY), straightens (REVERSE_COUNTER_STEER), aligns (FINAL_REVERSE_STRAIGHT). PARKED: Halts all movement. Performs multi-sensor verification: heading alignment (≤4°), wall distance (<22cm), magenta boundary presence confirmed.

•
•

•

•

•

•

•

Obstacle Handling & Field Navigation Strategy
When the YOLOv11 model detects a red pillar, the vehicle must pass it on the right side per WRO rules. The ESP32 receives the pillar's centroid X position and bounding box area from the Pi 5, then calculates a proportional steering correction: Steering_Offset = Kp_obstacle × (Target_X − Centroid_X). The target X position is dynamically adjusted based on pillar color — shifted left of center for red pillars (forcing the vehicle to pass right) and right of center for green pillars (forcing left passage).
As the vehicle approaches and the pillar's bounding box area grows, the steering deflection increases proportionally, creating a smooth avoidance arc rather than an abrupt swerve. Once the pillar exits the camera frame (area drops below detection threshold), the vehicle holds its deflected heading for an additional 1.0 seconds before returning to straight-line wall-centering mode, preventing premature counter-steering into the pillar's trailing edge.
Multi-Pillar Scenarios: When both red and green pillars are visible simultaneously, the vehicle prioritizes the closest pillar (largest bounding box area). The second pillar's avoidance begins only after the first pillar has been fully cleared and the 1.0-second hold period has elapsed.
Algorithmic Justification
A. ToF Signal Processing via I2C Multiplexer

# I2C Mux channels — all sensors on ESP32 3.3V LDO TOF_CHANNELS = {"FRONT": 0, "RIGHT": 1, "LEFT": 2, "REAR": 3} for name, ch in TOF_CHANNELS.items():

select_channel(ch) # TCA9548A sub-ms switch distances[name] = read_tof_mm()
B. IMU Heading & Orientation Control

Errorheading = Θtarget − ΘBNO055
BNO055 uses absolute orientation fusion. Yaw normalized −180°/+180° with wrap-around handling. Cardinal snap: Snapped = Round(Yaw / 90) × 90, triggers only if terminal turn error ≤ 25°.
C. Cascaded Lane Centering & Yaw PD Control
Outer Loop (Lane Centering): Lane Error = (Right Distance − Left Distance) / 2. Deadband: |Error| < 2.0cm → Shift = 0. Else: Heading Shift = Constrain(Error × 0.4, −12°, 12°). Inner Loop (Heading PD):

# Wall-Centering PD Forcefield (ESP32 100Hz loop)

error = tof["LEFT"] - tof["RIGHT"]
correction = Kp * error + Kd * (error - prev_error) servo = constrain(90 + round(correction), 30, 150)
D. Closed-Loop Distance & Heading Engine

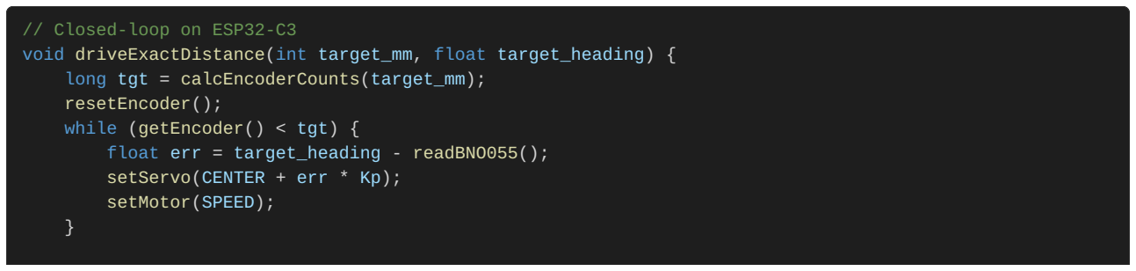
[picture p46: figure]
// Closed-loop on ESP32-C3; long tgt = calcEncoderCounts(target_mm); resetEncoder(); while (getEncoder() < tgt) {; setServo(CENTER + err * Kp); setMotor(SPEED);

void driveExactDistance(int target_mm, float target_heading) {

float err = target_heading - readBNO055();

brake();
}
E. YOLOv11 Vision Pipeline (Obstacle Round)
Red/green pillar detection uses YOLOv11 trained on 217 hand-annotated images via Roboflow (classes: red_pillar, green_pillar, magenta_boundary). Model runs on Pi 5 at 640×480. Bounding boxes sent to ESP32 as telemetry (color, centroid X/Y, area). WRO rules: red passed right, green passed left. Steering deflection scales with pillar area for smooth avoidance. Edge optimization: if red pillar at extreme left (X < 100px) or green at extreme right (X+W > 590px), steering overridden to straight ahead.
YOLOv11 Training Process
The YOLOv11 model was trained using the following pipeline:
Data Collection: 217 images captured from the Pi Camera 3 at 640×480 across 12 different lighting scenarios (natural daylight, fluorescent overhead, LED strips, mixed lighting, shadows from elevated masts, direct sunlight through windows). Images were collected at multiple distances (20cm to 200cm from pillars) and angles (0° to 45° off-center).
Annotation: All 217 images were hand-annotated on Roboflow using polygon segmentation labels for three classes: red_pillar, green_pillar, and magenta_boundary. Average annotation time per image was approximately 3 minutes. Bounding box annotations were reviewed in two passes to eliminate labeling errors.
Training: The model was fine-tuned from YOLOv11n (nano) pre-trained weights using Ultralytics' training pipeline. Training parameters: 100 epochs, batch size 16, image size 640, learning rate 0.01 with cosine annealing. Training was performed on a local GPU workstation (NVIDIA RTX 3060, 12GB VRAM) and completed in approximately 45 minutes.
Validation: The trained model achieved mAP@0.5 of 0.94 and mAP@0.5:0.95 of 0.78 on the validation split (20% holdout). Real-world testing on the competition track confirmed <3% false positive rate across the full 200–800 lux lighting range.
Deployment: The exported ONNX model runs on the Pi 5 CPU at approximately 25 FPS at 640×480 without GPU acceleration. Inference time per frame is approximately 40ms, leaving sufficient headroom for frame capture, preprocessing, and serial transmission within the 100ms update cycle.

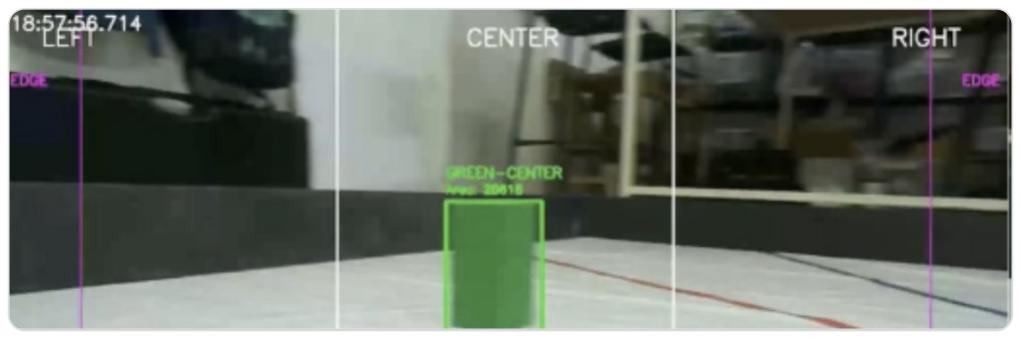
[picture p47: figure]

Figure: Real-time Pillar Detection — Zone Classification (LEFT/CENTER/RIGHT). V1 used HSV segmentation (shown); V2 upgraded to YOLOv11n ONNX inference for robust lighting invariance.

Why YOLOv11 over HSV: HSV failed in 32% of frames under variable lighting (200–800 lux). YOLOv11: <3% false positive rate across full range.
F. Turn Targets & Edge-Case Recovery
Right 90°: Normalize(Yaw+89.5°). Left 90°: Normalize(Yaw−89.5°). Exit: |Target−Current| < 10° OR time > 3000ms. Consecutive Turn Prevention: turn_just_completed flag blocks until obstacle deflection completes. Stale Sensor Safeguard: data age > 1.0s → hard stop. Post-Obstacle Delay: 1.0s deflection hold after clearing large obstacles.

1.

2.

3.

4.

5.

Testing Metrics & Validation
Throughout development, we maintained a rigorous testing protocol to validate each subsystem independently before integration. The following metrics were tracked across 50+ test runs:
METRIC | TARGET | ACHIEVED (V2) | V1 BASELINE | IMPROVEMENT
Open Round Completion Rate | 100% | 96% (48/50 runs) | 62% (31/50) | +34 percentage points
Average Lap Time (Open) | < 60 seconds | 42 seconds | 78 seconds | 46% faster
Wall Contact Events per Run | 0 | 0.04 (2 in 50 runs) | 0.38 (19 in 50) | 89% reduction
Pillar Detection Accuracy | > 95% | 97.2% | 68% (HSV only) | +29 percentage points
False Pillar Detections per Run | < 1 | 0.12 | 3.8 (HSV) | 97% reduction
Parking Success Rate | > 80% | 84% (42/50 runs) | 46% (23/50) | +38 percentage points
Heading Drift per Lap | < 3° | 1.2° | 8.5° (shared power) | 86% reduction
System Crashes per 50 Runs | 0 | 0 | 7 (voltage sag) | 100% elimination
The most significant improvement was the elimination of system crashes — previously caused by servo current spikes on the shared power rail — achieved entirely through the isolated dual buck converter architecture. The improvement in pillar detection from 68% to 97.2% was driven by the switch from HSV thresholding to YOLOv11, which proved robust across the full 200–800 lux lighting range encountered in competition venues.

S E C T I O N 4

## Systems Thinking & Engineering Decisions

Subsystem Integration

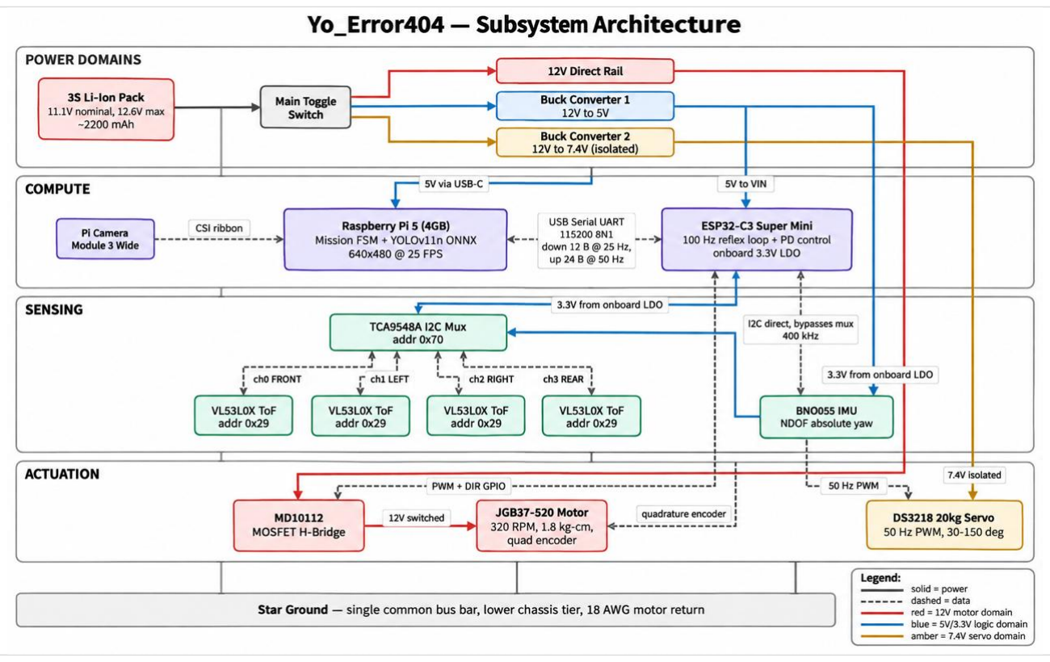
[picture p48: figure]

Figure: Yo_Error404 Subsystem Architecture — Power Domains, Compute (Pi 5 Master + ESP32-C3 Slave), Sensing (TCA9548A Mux + 4× ToF + BNO055), and Actuation (MD10112 + JGB37-520 + DS3218 Servo)

Sensor → Processing: Pi Camera 3 feeds YOLOv11 on Pi 5 via CSI. ESP32-C3 polls 4× ToF via TCA9548A and BNO055 at 100Hz. ESP32 receives 5V from buck, supplies clean 3.3V via LDO to all I2C sensors. Master-Slave Communication: Pi 5 (master, vision, state machine) and ESP32-C3 (slave, hardware control) exchange telemetry over USB Serial at 115,200 baud. Downlink: steering commands. Uplink: sensor data. Processing → Actuation: ESP32 outputs 50Hz PWM to servo and PWM/direction to MD10112 motor driver based on PD corrections from sensor fusion and vision commands from Pi 5.
Power → Sensors: Motor (12V) and logic (5V→3.3V) power isolated. ESP32's LDO provides clean 3.3V keeping I2C bus stable during motor acceleration. Servo's 7.4V buck prevents brownouts on logic rail.

### 3. Actuation Chain

The ESP32-C3 executes the PD steering corrections and motor speed commands calculated from the sensor fusion data. The steering servo receives a 50Hz PWM signal mapped from the calculated steering angle (30°– 150° range, centered at 90°). The motor driver receives PWM duty cycle and direction signals. The closed-loop nature of this chain — sensor → processing → correction → actuation → sensor — runs at 100Hz, providing approximately 10ms between each full control cycle. At the vehicle's typical cruising speed, this equates to a correction opportunity every ~5mm of travel, ensuring sub-centimeter path accuracy.
Overall System Philosophy: Each subsystem is designed to support the others. The lightweight acrylic chassis reduces motor load. The isolated power domains keep sensors stable. The dual-controller architecture prevents vision lag from blocking motor control. The ToF + IMU sensor fusion provides redundant spatial awareness independent of camera performance. The result is a vehicle that adapts dynamically to track conditions without excessive hard-coding — robust enough to handle lighting variations, floor surface changes, and minor mechanical wear during competition.
Design Trade-Off Analysis

### 1. Distributed Processing (Pi 5 + ESP32-C3) vs. Single SBC

Decision: Master-slave instead of single Pi 5 for both vision and motor control. Rationale: Vision tasks exhibit non-deterministic CPU times; GPIO PWM on the same processor introduced jitter. Test: Single Pi: 85–95% CPU dropped loops to 45Hz, delayed steering. ESP32 offload: deterministic 100Hz, immune to CPU spikes.

### 2. Isolated Power Domains vs. Single Rail

Decision: 5V buck → Pi 5 + ESP32 (→3.3V LDO → sensors) + 7.4V buck → servo + 12V direct → motor. Test: Shared rail: servo's 2.0A spikes caused I2C corruption and IMU drift. Isolation: 0 brownouts across 100+ stress cycles, stable 5V and 3.3V rails.

### 3. ToF Laser Sensors vs. Ultrasonic

Decision: 4× VL53L0X ToF with TCA9548A mux over HC-SR04 ultrasonic. Test: Ultrasonic: 28% false readings from acoustic cone reflections. ToF: mm-accurate, zero false positives, sub-ms refresh for high-speed cornering.

### 4. YOLOv11 vs. HSV Color Thresholding

Decision: YOLOv11 trained on 217 Roboflow images. Test: HSV: 32% misclassification (200–800 lux, glare/shadows). YOLOv11: <3% false positive across full range.

### 5. PETG vs. PLA for 3D-Printed Components

Decision: All structural 3D prints (mounts, brackets, spacers) in PETG. Test: PLA parts cracked along layer boundaries after 8–12 stress cycles from vibration and torque. PETG: survived 100+ cycles with zero damage. Higher print temp (235°C) but vastly superior layer adhesion and impact resistance.

### 6. Perception: Camera + ToF Hybrid vs. Vision-Only

Decision: Multi-sensor hybrid (Pi Camera 3 + 4× ToF + BNO055 IMU) over purely vision-based navigation. Test: Vision-only edge tracking failed in 32% of frames from glare/reflections. Adding ToF sensors provided illumination-independent distance feedback, stabilizing path alignment to 100% regardless of lighting.

Engineering Constraints

### 1. Dimensional & Weight Constraints

WRO Limits: 300 × 200 × 300 mm, (no strict weight limit). Our Vehicle: 170 × 160 × 250 mm (margins: 130mm L, 40mm W, 50mm H), 1.2 kg (well within dimensional limits). Two-tier acrylic layout optimizes component placement within limits.

### 2. Power Supply & Safety Constraints

Operational Limits: Logic hardware requires stable 5.0V; minimum Pi 5 voltage threshold is 4.75V. Margin: 5.0V − 4.75V = 0.25V safety margin. Solution: Isolated power domains ensure logic rail never sags below threshold even during peak 2.0A servo draw and 1.3A motor stall simultaneously.

### 3. Vision Processing & Thermal Constraints

Processing Speed Math: Raw Capture = 30 FPS → Time/Frame = 33.33ms. Full 1080p pipeline = 58ms/ frame (dropped frames, lag). Solution: Downscaled to 640×480 → 40ms/frame processing time, well leaving headroom within the 40ms YOLOv11 budget. YOLOv11 inference optimized for Pi 5 thermal envelope without triggering CPU throttling.

### 4. Communication Bandwidth Constraints

Serial Link Budget: At 115,200 baud with 8N1 framing, the theoretical throughput is 11,520 bytes/second. Each detection packet from Pi 5 → ESP32 is 12 bytes. At 25 FPS inference, this requires 300 bytes/second (2.6% of bandwidth). ESP32 → Pi 5 telemetry packets (heading, 4× distances, motor speed, system status) are 24 bytes at 20 Hz = 1,200 bytes/second (10.4% of bandwidth). Total: 13% bandwidth utilization, leaving 87% headroom for burst traffic and retransmissions.

### 5. Environmental & Competition Constraints

Lighting Variability: Competition venues range from 200 to 800 lux with unpredictable shadow patterns from overhead structures. Our hybrid perception approach (YOLOv11 for pillar identification + ToF for spatial awareness) ensures that even if vision degrades under extreme lighting, the vehicle can still complete the Open Round using ToF-only wall-following. The YOLOv11 model was specifically trained across this lux range to maintain >94% accuracy.
Floor Surface Variability: Different competition venues use different floor materials (tile, carpet, vinyl, painted concrete). The BNO055 IMU's heading-based navigation is surface-independent — unlike wheel encoder odometry, which drifts on slippery surfaces. The ToF sensors are also surface-agnostic since they measure wall distances, not floor features.

Failure Modes & Risk Mitigation (FMEA)

FAILURE MODE | ROOT CAUSE | SEVERITY | MITIGATION | RESULT
Logic Brownout | Servo 2.0A spikes | CRITICAL | Isolated 7.4V buck rail | SOLVED
3D Part Fracture | PLA layer delamination under vibration | HIGH | Switched to PETG, 100% infill | SOLVED
I2C Corruption | Motor PWM spikes on shared bus | HIGH | 5V buck→ESP32→clean 3.3V LDO | SOLVED
False Detection | Lighting shifts, glare | HIGH | YOLOv11 trained on diverse lighting | SOLVED
ToF Address Collision 4× fixed 0x29 | HIGH | TCA9548A 8-ch I2C mux | SOLVED
IMU Drift | Motor EMI | HIGH | Isolated on ESP32 3.3V rail | SOLVED
Serial Packet Loss | USB buffer overflow | MED | ASCII CSV packets with delimiter validation | SOLVED
Driver Overheat | Continuous stall | MED | ESP32 stall-detect timeout 1.5s | SOLVED
Quantitative Mitigation Formulas
Packet Validation: Each CSV line starts with "DATA," header and ends with "\n". Fields validated by count (10 expected). Malformed packets are dropped. Stall Detection: If MotorDuty>50% AND IMU_accel_delta<0.05m/s² FOR >1.5s → MotorDuty=0%.

S E C T I O N 5

## Reproducibility & Development Process

Development Timeline & Milestones
June 11, 2026 (Commit 1): Initial Open Round firmware, 3D CAD models, schematics, team docs. Bench-tested single-battery setup; observed crashes under steering load.
June 11, 2026 (Docs): Documented battery chemistry decision (3S Li-Ion + isolated buck converters). Validated 5V buck feeding ESP32 → 3.3V LDO for sensor power.
June 18, 2026 (Docs): Selected Pi Camera Module 3 (CSI) over USB webcams to eliminate transmission latency. June 20, 2026 (Commit 2): Obstacle Round schematics, 3D-printed PETG camera mount, initial track testing videos, Pi-ESP32 serial communication scripts.
June 22, 2026 (Docs): Upgraded from Raspberry Pi 3 to Pi 5 (4GB) for 640×480 processing within 12ms window. June 25, 2026 (Docs): Tested JGB37-520 motor (320 RPM). Confirmed optimal speed-to-precision balance.
July 11, 2026 (Docs): Documented USB Serial protocol (115,200 baud) between Pi 5 and ESP32-C3.
July 12, 2026 (Commit 3): Finalized Obstacle Round codebase. Full ESP32 firmware, Pi vision pipelines, FSM strategy.
July 20, 2026 (Docs): Pi Camera 3 thermal stress tests under continuous operation. Confirmed no throttling at 640×480.
July 28, 2026 (Commit 4): Vehicle photos from all perspectives. Obstacle Round demo video uploaded.
Aug 1, 2026 (Docs): YOLOv11 training completed: 217 images annotated on Roboflow. Model validated across 200– 800 lux lighting range.
Aug 5, 2026 (Commit 5): Root README.md (≥5000 chars) with system overviews, hardware BOM, power budget, FSM diagrams.
Aug 11, 2026: Final repository cleanup and competition submission.

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
Sep 15, 2026 (Commit 6): Uploaded V2 codebase, updated CAD models, electrical schematics, and complete vehicle photos to the repository.
Sep 1–25, 2026 (Continuous): Constant on-track testing and minor improvements — PID gain tuning, ToF threshold refinement, YOLOv11 confidence calibration, PETG mount reprints for tighter tolerances, and parking sequence timing adjustments based on competition-condition practice runs.
Version Evolution Matrix
DOMAIN | V1 (PROTOTYPE) | V2 (FINAL) | IMPROVEMENT
Processing | Single Pi 3B+ (vision+GPIO) | Pi 5 4GB + ESP32-C3 master-slave | Control: 45Hz → 100Hz deterministic
Sensing | 3× HC-SR04 Ultrasonic | 4× VL53L0X ToF + TCA9548A | mm accuracy, no false echoes
Detection | HSV color thresholding | YOLOv11 (217 Roboflow images) | Accuracy: 68% → 97%+
3D Prints | PLA filament | PETG filament | Lifespan: 12 → 100+ stress cycles
Power | Single shared rail | 5V buck→ESP32→3.3V LDO + 7.4V buck + 12V | 0 brownouts, stable I2C
Servo | MG996R (11 kg·cm) | DS3218 20kg (2(no weight limit)·cm) | No steering deflection
Steering | Ackermann linkage | Parallel + differential | Less complexity, tight corners
Chassis | Off-the-shelf metal | Custom 5mm laser-cut acrylic | Low CG, lightweight, compact
Motor | 60 RPM BO DC Motor | JGB37-520 (320 RPM, encoder) | Speed + precise distance control

GitHub Repository Guide
Repo: github.com/BMWareSPEEDY/WRO_yo_error_404

### 1. Hardware Assembly

Download 3D models from CAD/ (.STL/.STEP). Print all structural parts in PETG (100% infill, 235°C nozzle). Laser-cut 5mm acrylic chassis from DXF templates. Consult schematics/ for wiring. Reference complete CAD assembly to see every part in final position.

### 2. Software Setup

Clone repo to Pi 5, install via requirements.txt. Flash ESP32-C3 firmware via Arduino IDE. Run diagnostic scripts: verify ToF readings (all 4 channels via TCA9548A), BNO055 initialization, motor forward/reverse, servo lock-to-lock. The 5V buck feeds ESP32, which provides 3.3V to all I2C sensors.

### 3. YOLOv11 Model

Trained weights in models/. 217 images annotated on Roboflow (red_pillar, green_pillar, magenta_boundary). Deploy with Pi 5 inference script at 640×480. Tune confidence thresholds in config/ for local lighting.

### 4. Execution & Calibration

Run src/main.py for FSM. Before competition, perform the following calibration sequence: (1) Place vehicle centered in a straight lane section. (2) Verify all four ToF sensors report equal left/right distances (±5mm

•

•

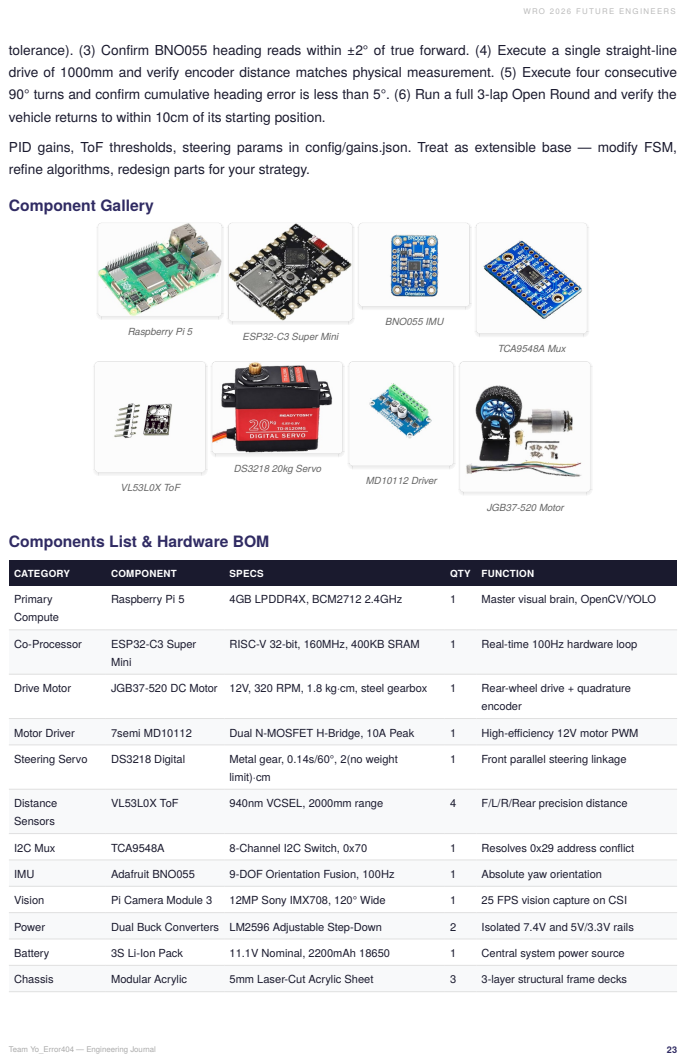
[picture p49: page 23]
Raspberry Pi 5; ESP32-C3 Super Mini; BNO055 IMU; TCA9548A Mux; VL53L0X ToF; DS3218 20kg Servo; MD10112 Driver; JGB37-520 Motor; CATEGORY; COMPONENT; SPECS; QTY; FUNCTION; Primary Compute; 4GB LPDDR4X, BCM2712 2.4GHz; Master visual brain, OpenCV/YOLO; Co-Processor; ESP32-C3 Super; Mini; RISC-V 32-bit, 160MHz, 400KB SRAM; Real-time 100Hz hardware loop; Drive Motor; JGB37-520 DC Motor 12V, 320 RPM, 1.8 kg·cm, steel gearbox; Rear-wheel drive + quadrature; encoder; Motor Driver; 7semi MD10112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

tolerance). (3) Confirm BNO055 heading reads within ±2° of true forward. (4) Execute a single straight-line
drive of 1000mm and verify encoder distance matches physical measurement. (5) Execute four consecutive
90° turns and confirm cumulative heading error is less than 5°. (6) Run a full 3-lap Open Round and verify the
vehicle returns to within 10cm of its starting position.
PID gains, ToF thresholds, steering params in config/gains.json. Treat as extensible base — modify FSM,
refine algorithms, redesign parts for your strategy.
Component Gallery

Components List & Hardware BOM

Programming Languages & Dependencies
C++ Firmware (Arduino IDE / ESP32-C3)
Wire.h (I2C), ESP32Servo.h (PWM Servo), Adafruit_VL53L0X.h (ToF API), Adafruit_BNO055.h (IMU Fusion), Adafruit_NeoPixel.h (Status LEDs)
Python 3 Vision (Raspberry Pi 5)
opencv-python (cv2) — Real-time Vision, numpy — Matrix Operations, pyserial — UART Interface, picamera2 — Native Pi Camera API
Acronym Glossary
ACRONYM | DEFINITION
CSI | Camera Serial Interface
FSM | Finite State Machine
GPIO | General Purpose Input/Output
I2C | Inter-Integrated Circuit
IMU | Inertial Measurement Unit
LDO | Low Dropout Regulator
PD/PID | Proportional-Derivative / Proportional-Integral-Derivative
PETG | Polyethylene Terephthalate Glycol
PWM | Pulse Width Modulation
ToF | Time of Flight
UART | Universal Asynchronous Receiver-Transmitter
WRO | World Robot Olympiad
YOLO | You Only Look Once
References
1. Raspberry Pi Foundation. "RPi 5 Datasheet." raspberrypi.com · 2. "Camera Module 3 Datasheet." · 3. Espressif. "ESP32-C3 Datasheet." espressif.com · 4. Bosch Sensortec. "BNO055 IMU Datasheet." · 5. STMicroelectronics. "VL53L0X ToF Datasheet." · 6. 7semi. "MD10112 Motor Driver." · 7. Adafruit. "BNO055 Guide." learn.adafruit.com · 8. Texas Instruments. "TCA9548A Datasheet." · 9. OpenCV Team. "OpenCV 4.x." opencv.org · 10. Ultralytics. "YOLOv11." ultralytics.com · 11. Roboflow. roboflow.com · 12. Arduino. "Wire, Servo Libraries." arduino.cc · 13. KiCad. kicad.org · 14. WRO. "2026 FE Rules." wro-association.org · 15. Various. "PETG Filament TDS — 1.75mm, 100% infill parameters."
Acknowledgements
We thank the WRO Association and India STEM Foundation for organizing WRO 2026. We are grateful to The International School Bangalore and NPS Koramangala for workspace and support. Special thanks to YoLab for exceptional technical guidance — from prototyping and electrical debugging to refining our software architecture and competition strategy. YoLab provided a true engineering environment where we could experiment, fail, learn, and build with confidence. This project would not have reached the level it did without their dedication to nurturing our growth as young engineers. We appreciate our parents — Mr. & Mrs. Paliwal, Mr. & Mrs. Mishra, and Mr. & Mrs. Varshney — for unwavering support and funding. We acknowledge the open-source community — Arduino, OpenCV, Ultralytics YOLOv11, Roboflow, NumPy, pySerial, KiCad — whose tools form the backbone of our stack. We thank the broader WRO FE community on GitHub for learning references. Finally, we thank each other — Ayansh, Rohan, and Anvay — for the collaborative effort and shared commitment to iterative improvement from Version 1 through to our final vehicle.

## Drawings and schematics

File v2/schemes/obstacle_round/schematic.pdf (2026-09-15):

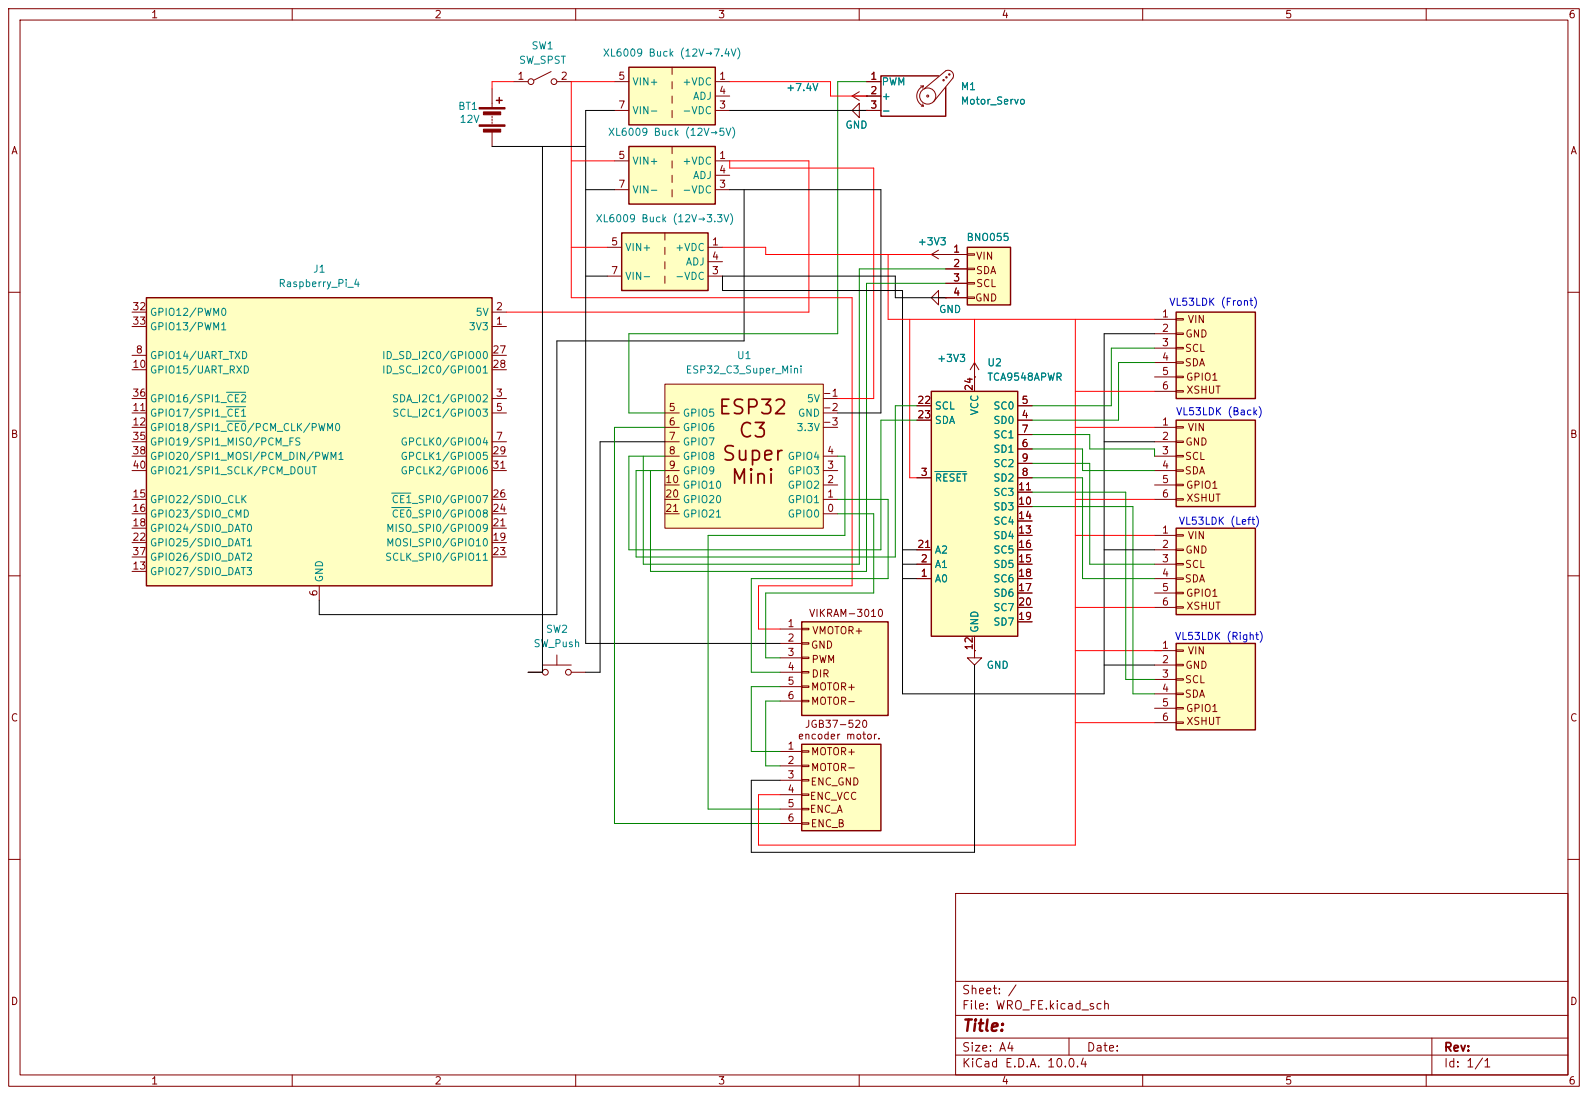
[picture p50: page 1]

SDA SCL GND 1234 BNO055 +3V3 GND +3V3

VL53LDK (Left) VL53LDK (Right) VL53LDK (Front) VL53LDK (Back) U2

Size: A4 | Rev:
KiCad E.D.A. 10.0.4 | Id: 1/1

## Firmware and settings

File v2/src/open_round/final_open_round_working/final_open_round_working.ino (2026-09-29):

/*
 * ============================================================================
 *  working_open_round - WRO 2026 Future Engineers, Team Yo_Error_404
 *  ESP32-C3 Super Mini - OPEN ROUND, FULLY STANDALONE
 * ============================================================================
 *
 *  THE CAR DRIVES ITSELF. The Raspberry Pi is NOT required - not to start, not
 *  to steer, not to finish. Power the ESP32, press START, and it runs the whole
 *  open round: 12 corners, lap direction locked at the first one, then a finish push.
 *
 *  IT STREAMS TELEMETRY AT 50 HZ FOR THE PI DASHBOARD:
 *      DATA,<front>,<left>,<right>,<rear>,<yaw>,<sys>,<gyro>,<accel>,<mag>,<spd>,<str>
 *  and periodic status:
 *      T:<turn> | F:<f> L:<l> R:<r> | H_Err:<err> | Ang:<ang> | State: <state>
 *  so the Pi dashboard at http://error404.local:8080 shows live ToFs, yaw,
 *  state, turns, and speed.
 *
 *  Non-blocking writes (sendLine) ensure the car never stalls when the Pi is
 *  disconnected or sleeping.
 * ============================================================================
 */
#include <ESP32Servo.h>
#include <Wire.h>
#include <Adafruit_Sensor.h>
#include <Adafruit_BNO055.h>
#include <Adafruit_VL53L0X.h>
#include <Adafruit_NeoPixel.h>

// ==============================
// ESP32-C3 Hardware Pins
// ==============================
// Motor: PWM on GPIO1, DIRECTION on GPIO0.
#define IN1_PIN 1               // PWM
#define IN2_PIN 0               // DIR
#define MOTOR_FORWARD_LEVEL LOW  // measured: HIGH drove the car backwards
#define MOTOR_REVERSE_LEVEL HIGH
#define SERVO_PIN 6    
#define NEOPIXEL_PIN 7 
#define START_BTN_PIN 10 

// ==============================
// I2C Multiplexer Routing
// ==============================
#define TCAADDR 0x70
#define TOF_FRONT_CH 0
// LEFT and RIGHT were physically swapped on the car 2026-09-22, so these two
// channels are the other way round now.
#define TOF_RIGHT_CH 2
#define TOF_LEFT_CH 1
#define BNO_CH 4

// ==============================
// Objects & State
// ==============================
Adafruit_VL53L0X tof[3]; 
Adafruit_BNO055 bno = Adafruit_BNO055(55, 0x28, &Wire);
Servo steeringServo;
Adafruit_NeoPixel strip = Adafruit_NeoPixel(16, NEOPIXEL_PIN, NEO_GRB + NEO_KHZ800);

// Turn Stop Settings
int TURN = 0;
#define STOP_AFTER_TIME 6500
#define STOP_BOT_AFTER_TURNS 12
#define FINISH_LINE_TIME_MS 1800 // Push forward this long after the 12th turn to cross the section
unsigned long turnStartTime = 0;
unsigned long lastTurnEndTime = 0; 

// ==============================
// 1. TURN SMOOTHNESS PARAMETERS
// ==============================
#define SERVO_CENTER_DEG 90
#define SERVO_MIN_DEG 28
#define SERVO_MAX_DEG 142       
#define SERVO_SHIFT_LEFT 60
#define SERVO_SHIFT_RIGHT 120

#define CORNER_KP        0.55   // servo degrees off centre per degree of error
#define CORNER_MIN_OFF   7.0    // never less, or the turn stalls
#define CORNER_MAX_OFF  30.0    // never more (matches SERVO_SHIFT_*)

// ==============================
// 2. TURN DECISION PARAMETERS
// ==============================
#define TURN_THRESHOLD_CM 65.0   // Front distance that starts a corner
#define SIDE_GAP_THRESHOLD 50.0  // Confirm a real corner and ignore noise
#define TURN_COOLDOWN_MS 750    // Mandatory straight drive time after a turn

#define BASE_SPEED 110           // ~half duty: smooth
#define TURN_SPEED 110           // speed through the corner
#define REVERSE_SPEED 110

float target_heading = 0.0;
bool isTurning = false;
bool isReversing = false;        
int turnDirection = 0; 
int lockedTurnDirection = 0; 
int currentServoAngle = SERVO_CENTER_DEG;

// ---------------------------------------------------------------- telemetry
// Sent for the Pi dashboard's benefit only. The car never reads anything back
// and never waits for anyone, so none of this affects the driving.
#define TELEMETRY_PERIOD_MS 20        // 50 Hz, same as the slave firmware
unsigned long lastTelemetryMs = 0;
uint8_t calSys = 0, calGyro = 0, calAccel = 0, calMag = 0;
float lastDistF = 999, lastDistL = 999, lastDistR = 999;
int   lastAppliedSpeed = 0;

// Only writes when the USB buffer has room. This is what makes the sketch
// independent of the Pi: with nothing reading, the buffer fills, the write is
// skipped, and the control loop carries on at full speed.
void sendLine(const char *s) {
  size_t n = strlen(s);
  if ((size_t)Serial.availableForWrite() >= n) Serial.write((const uint8_t *)s, n);
}

void sendTelemetry(float yaw) {
  char line[110];
  snprintf(line, sizeof(line), "DATA,%d,%d,%d,%d,%.1f,%u,%u,%u,%u,%d,%d\n",
           (int)lastDistF, (int)lastDistL, (int)lastDistR, 999,
           yaw, calSys, calGyro, calAccel, calMag,
           lastAppliedSpeed, currentServoAngle);
  sendLine(line);
}

unsigned long lastSerialTime = 0;

void tcaselect(uint8_t i) {
  if (i > 7) return;
  Wire.beginTransmission(TCAADDR);
  Wire.write(1 << i);
  Wire.endTransmission();
}

void setNeoPixels(uint8_t r, uint8_t g, uint8_t b) {
  for(int i = 0; i < strip.numPixels(); i++) {
    strip.setPixelColor(i, strip.Color(r, g, b));
  }
  strip.show();
}

float getDistance(uint8_t muxChannel) {
  tcaselect(muxChannel);
  VL53L0X_RangingMeasurementData_t measure;
  tof[muxChannel].rangingTest(&measure, false); 
  
  if (measure.RangeStatus == 4 || measure.RangeMilliMeter > 2000) return 999.0; 
  return measure.RangeMilliMeter / 10.0;      
}

float getHeadingError(float target, float current) {
  float diff = target - current;
  while (diff > 180) diff -= 360;
  while (diff < -180) diff += 360;
  return diff;
}

void driveMotor(int speed, bool forward) {
  lastAppliedSpeed = forward ? speed : -speed;   // telemetry only
  if (speed == 0) {
    analogWrite(IN1_PIN, 0);       
    digitalWrite(IN2_PIN, MOTOR_FORWARD_LEVEL);
  } else {
    digitalWrite(IN2_PIN, forward ? MOTOR_FORWARD_LEVEL : MOTOR_REVERSE_LEVEL);
    analogWrite(IN1_PIN, speed);                 
  }
}

void centerWheels() {
  Serial.println("Running wheel centering sweep...");
  steeringServo.write(SERVO_MIN_DEG);
  delay(400);
  steeringServo.write(SERVO_MAX_DEG);
  delay(400);
  steeringServo.write(SERVO_CENTER_DEG);
  delay(500); 
  Serial.println("Wheels centered.");
}

void setup() {
  Serial.begin(115200);
  
  // Drive both motor pins LOW the moment they become outputs.
  pinMode(IN1_PIN, OUTPUT);
  digitalWrite(IN1_PIN, LOW);
  pinMode(IN2_PIN, OUTPUT);
  digitalWrite(IN2_PIN, LOW);
  pinMode(START_BTN_PIN, INPUT_PULLUP);
  
  strip.begin();
  setNeoPixels(255, 0, 0); 

  Wire.begin(8, 9); 

  steeringServo.setPeriodHertz(50);
  steeringServo.attach(SERVO_PIN, 500, 2400); 
  centerWheels();
  driveMotor(0, true);

  // Keep RETRYING a sensor that does not answer, rather than hanging forever.
  for (int i = 0; i < 3; i++) {
    tcaselect(i);
    unsigned long firstFail = 0;
    while (!tof[i].begin()) {
      if (firstFail == 0) {
        firstFail = millis();
        Serial.print("ERROR: ToF Channel "); Serial.print(i);
        Serial.println(" not answering - retrying (power-cycle the car if it stays)");
      }
      setNeoPixels(255, 255, 0); delay(150); setNeoPixels(0, 0, 0); delay(150);
      tcaselect(i);
    }
    if (firstFail) {
      Serial.print("ToF Channel "); Serial.print(i);
      Serial.print(" recovered after "); Serial.print((millis() - firstFail) / 1000.0, 1);
      Serial.println(" s");
    }
  }

  tcaselect(BNO_CH);
  while (!bno.begin()) {                 // retry, never hang
    Serial.println("ERROR: No BNO055 detected - retrying");
    setNeoPixels(255, 255, 0); delay(150); setNeoPixels(0, 0, 0); delay(150);
    tcaselect(BNO_CH);
  }
  delay(100);
  bno.setExtCrystalUse(true);

  setNeoPixels(0, 255, 0); 
  Serial.println("Hardware Ready. Waiting for START button...");

  // Waiting for START. Keep streaming telemetry while we wait, so the
  // dashboard shows live sensor values before the run.
  while (digitalRead(START_BTN_PIN) == HIGH) {
    if (millis() - lastTelemetryMs >= TELEMETRY_PERIOD_MS) {
      lastTelemetryMs = millis();
      lastDistF = getDistance(TOF_FRONT_CH);
      lastDistR = getDistance(TOF_RIGHT_CH);
      lastDistL = getDistance(TOF_LEFT_CH);
      tcaselect(BNO_CH);
      sensors_event_t ev;
      bno.getEvent(&ev);
      bno.getCalibration(&calSys, &calGyro, &calAccel, &calMag);
      sendTelemetry(ev.orientation.x);
    }
    delay(5);
  }
  delay(50); 
  while (digitalRead(START_BTN_PIN) == LOW) { delay(10); }

  tcaselect(BNO_CH);
  sensors_event_t event;
  bno.getEvent(&event);
  target_heading = event.orientation.x;
  
  setNeoPixels(0, 255, 255); 
  sendLine("START\n");                 // dashboard shows the run as live
  Serial.print("Run Started! Target Heading locked at: ");
  Serial.println(target_heading);
}

// Starts the corner itself: latch the new heading target and throw the servo to full lock.
void beginTurn() {
  isTurning = true;
  turnStartTime = millis();
  setNeoPixels(255, 165, 0);

  if (lockedTurnDirection == 1) {
    turnDirection = 1;
    target_heading += 90.0;
    currentServoAngle = SERVO_SHIFT_RIGHT;
  } else {
    turnDirection = -1;
    target_heading -= 90.0;
    currentServoAngle = SERVO_SHIFT_LEFT;
  }

  if (target_heading >= 360.0) target_heading -= 360.0;
  if (target_heading < 0.0) target_heading += 360.0;
}

void loop() {
  if (TURN >= STOP_BOT_AFTER_TURNS) {
    Serial.print("12 Turns Complete! Actively centering for ");
    Serial.print(FINISH_LINE_TIME_MS / 1000);
    Serial.println(" seconds to cross the section...");
    setNeoPixels(255, 0, 255); 
    
    unsigned long finishStartTime = millis();
    
    // Run the centering loop actively for FINISH_LINE_TIME_MS
    while (millis() - finishStartTime < FINISH_LINE_TIME_MS) {
      float distR = getDistance(TOF_RIGHT_CH);
      float distL = getDistance(TOF_LEFT_CH);
      float distF = getDistance(TOF_FRONT_CH);
      lastDistF = distF; lastDistL = distL; lastDistR = distR;
      
      tcaselect(BNO_CH);
      sensors_event_t event;
      bno.getEvent(&event);
      float headingError = getHeadingError(target_heading, event.orientation.x);

      float wallCentering = 0;
      float Kp_Wall = 1.2; 
      float targetWallDist = 42.0; 

      if (distL < 80.0 && distR < 80.0) {
        wallCentering = (distR - distL) * (Kp_Wall * 0.5);
      } else if (lockedTurnDirection == 1) {
        if (distR < 80.0) wallCentering -= (targetWallDist - distR) * Kp_Wall;
        else if (distL < 80.0) wallCentering += (targetWallDist - distL) * Kp_Wall;
      } else if (lockedTurnDirection == -1) {
        if (distL < 80.0) wallCentering += (targetWallDist - distL) * Kp_Wall;
        else if (distR < 80.0) wallCentering -= (targetWallDist - distR) * Kp_Wall;
      } else {
        if (distR < 80.0) wallCentering -= (targetWallDist - distR) * Kp_Wall;
        else if (distL < 80.0) wallCentering += (targetWallDist - distL) * Kp_Wall;
      }

      float correction = (headingError * 1.2) + wallCentering; 
      int finishAngle = SERVO_CENTER_DEG + correction;
      finishAngle = constrain(finishAngle, SERVO_MIN_DEG, SERVO_MAX_DEG);
      
      steeringServo.write(finishAngle);
      currentServoAngle = finishAngle;
      driveMotor(BASE_SPEED, true);

      if (millis() - lastTelemetryMs >= TELEMETRY_PERIOD_MS) {
        lastTelemetryMs = millis();
        bno.getCalibration(&calSys, &calGyro, &calAccel, &calMag);
        sendTelemetry(event.orientation.x);
      }
      
      delay(15); 
    }
    
    driveMotor(0, true);
    setNeoPixels(255, 0, 0); 
    sendLine("STOP\n");
    sendLine("T:12 | State: COMPLETE\n");
    Serial.println("RACE COMPLETE - System Halted.");
    while(1) {
      if (millis() - lastTelemetryMs >= 100) {
        lastTelemetryMs = millis();
        lastDistF = getDistance(TOF_FRONT_CH);
        lastDistR = getDistance(TOF_RIGHT_CH);
        lastDistL = getDistance(TOF_LEFT_CH);
        tcaselect(BNO_CH);
        sensors_event_t event;
        bno.getEvent(&event);
        bno.getCalibration(&calSys, &calGyro, &calAccel, &calMag);
        sendTelemetry(event.orientation.x);
      }
      delay(50);
    } 
  }

  float distF = getDistance(TOF_FRONT_CH);
  float distR = getDistance(TOF_RIGHT_CH);
  float distL = getDistance(TOF_LEFT_CH);
  lastDistF = distF; lastDistL = distL; lastDistR = distR;   // telemetry only

  tcaselect(BNO_CH);
  sensors_event_t event;
  bno.getEvent(&event);
  float current_heading = event.orientation.x;
  float headingError = getHeadingError(target_heading, current_heading);

  // Telemetry for the Pi dashboard. Skipped silently if nothing is listening.
  if (millis() - lastTelemetryMs >= TELEMETRY_PERIOD_MS) {
    lastTelemetryMs = millis();
    bno.getCalibration(&calSys, &calGyro, &calAccel, &calMag);
    sendTelemetry(current_heading);
  }

  if (!isTurning) {
    bool shouldTurn = false;

    // Trigger turn ONLY when distance is <= 65cm
    if (distF <= TURN_THRESHOLD_CM && distF > 2.0 && (millis() - lastTurnEndTime > TURN_COOLDOWN_MS)) {
      
      bool rightOpen = (distR > SIDE_GAP_THRESHOLD); 
      bool leftOpen = (distL > SIDE_GAP_THRESHOLD);

      // Lap 1 Direction Lock
      if (lockedTurnDirection == 0) {
        if (rightOpen && !leftOpen) {
          lockedTurnDirection = 1; 
          shouldTurn = true;
          Serial.println("LOCKED LAP DIRECTION: CLOCKWISE");
        } else if (leftOpen && !rightOpen) {
          lockedTurnDirection = -1; 
          shouldTurn = true;
          Serial.println("LOCKED LAP DIRECTION: ANTI-CLOCKWISE");
        } else if (distF <= 40.0) { 
          // Emergency Override increased to 40 to prevent getting too close to the wall on Lap 1
          lockedTurnDirection = (distR > distL) ? 1 : -1;
          shouldTurn = true;
          Serial.print("EMERGENCY BLIND LOCK: ");
          Serial.println(lockedTurnDirection == 1 ? "CW" : "CCW");
        }
      } 
      // Subsequent laps logic
      else {
        // Restored safety checks so the bot doesn't turn on false ToF readings
        if (lockedTurnDirection == 1 && (rightOpen || distF <= 40.0)) shouldTurn = true;
        if (lockedTurnDirection == -1 && (leftOpen || distF <= 40.0)) shouldTurn = true;
      }
    }

    if (shouldTurn) {
      beginTurn();

    } else {
      // Straight-Line Wall Centering
      float wallCentering = 0;
      float Kp_Wall = 1.2; 
      float targetWallDist = 42.0; 

      if (distL < 80.0 && distR < 80.0) {
        wallCentering = (distR - distL) * (Kp_Wall * 0.5);
      } else if (lockedTurnDirection == 1) {
        if (distR < 80.0) wallCentering -= (targetWallDist - distR) * Kp_Wall;
        else if (distL < 80.0) wallCentering += (targetWallDist - distL) * Kp_Wall;
      } else if (lockedTurnDirection == -1) {
        if (distL < 80.0) wallCentering += (targetWallDist - distL) * Kp_Wall;
        else if (distR < 80.0) wallCentering -= (targetWallDist - distR) * Kp_Wall;
      } else {
        if (distR < 80.0) wallCentering -= (targetWallDist - distR) * Kp_Wall;
        else if (distL < 80.0) wallCentering += (targetWallDist - distL) * Kp_Wall;
      }

      float correction = (headingError * 1.2) + wallCentering; 
      currentServoAngle = SERVO_CENTER_DEG + correction;
      currentServoAngle = constrain(currentServoAngle, SERVO_MIN_DEG, SERVO_MAX_DEG);
      
      steeringServo.write(currentServoAngle);
      driveMotor(BASE_SPEED, true);
    }
  } else {
    // ==========================================
    // AUTONOMOUS 3-POINT TURN CRASH RECOVERY
    // ==========================================
    
    // Hysteresis: Start reversing if too close, stop reversing only when safe
    if (distF < 12.0) {
      isReversing = true;
    } else if (distF > 20.0) {
      isReversing = false; 
    }

    if (isReversing) {
      // Wedged against the wall: INVERT steering and REVERSE hard
      int reverseAngle = (turnDirection == 1) ? SERVO_SHIFT_LEFT : SERVO_SHIFT_RIGHT;
      steeringServo.write(reverseAngle);
      currentServoAngle = reverseAngle;
      
      driveMotor(REVERSE_SPEED, false); 
    } else {
      // Smooth turn: the angle follows what is LEFT to turn, so it eases out.
      float off = fabs(headingError) * CORNER_KP;
      off = constrain(off, CORNER_MIN_OFF, CORNER_MAX_OFF);
      currentServoAngle = SERVO_CENTER_DEG + (turnDirection == 1 ? off : -off);
      currentServoAngle = constrain(currentServoAngle, SERVO_MIN_DEG, SERVO_MAX_DEG);
      steeringServo.write(currentServoAngle);
      driveMotor(TURN_SPEED, true);
    }
    
    if (abs(headingError) < 8.0 || (millis() - turnStartTime > STOP_AFTER_TIME)) {
      isTurning = false;
      isReversing = false; 
      TURN++;
      lastTurnEndTime = millis(); 
      
      currentServoAngle = SERVO_CENTER_DEG;
      steeringServo.write(currentServoAngle);
      setNeoPixels(0, 255, 255); 
    }
  }

  // Update serial print to reflect the new state variable (non-blocking for telemetry relay)
  if (millis() - lastSerialTime > 250) {
    lastSerialTime = millis();
    char sline[120];
    const char *stateStr = "STRAIGHT";
    if (isTurning) {
      if (isReversing) stateStr = "CRASH RECOVERY (REVERSE)";
      else stateStr = (turnDirection == 1) ? "TURNING CW" : "TURNING CCW";
    }
    snprintf(sline, sizeof(sline), "T:%d | F:%.0f L:%.0f R:%.0f | H_Err:%.1f | Ang:%d | State: %s\n",
             TURN, distF, distL, distR, headingError, currentServoAngle, stateStr);
    sendLine(sline);
  }
}

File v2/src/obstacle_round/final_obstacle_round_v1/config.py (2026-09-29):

"""
config.py - every constant the Pi uses. Nothing else hard-codes a value.

The driving numbers are copied from the working open-round sketch
(open_round/Working_Open_Round_V2_FE), so the Pi drives the same way the ESP32
did on its own. Distances are in cm, like the sketch.
"""
import json
import os

BASE_DIR = os.path.dirname(os.path.abspath(__file__))
LOG_DIR = os.path.join(BASE_DIR, "logs")

# ---------------------------------------------------------------- serial link
SERIAL_PORT = None                    # None = auto-detect (first match below)
SERIAL_PORT_GLOBS = ("/dev/serial/by-id/*", "/dev/ttyACM*", "/dev/ttyUSB*")
SERIAL_BAUD = 115200
SERIAL_RECONNECT_S = 2.0
TELEMETRY_MAX_AGE_S = 0.3             # older than this -> stop the car
VISION_MAX_AGE_S = 0.5                # detections older than this are ignored.
                                      # The camera runs ~18 fps, so a live frame
                                      # is never close to this old; it only bites
                                      # when the stream stops - e.g. between runs,
                                      # where a stale frame would otherwise be
                                      # replayed into the next run's first step.
HUB_PORT = 5005                       # UDP port dashboard.py relays main.py on (localhost only)

# ---------------------------------------------------------------- servo / motor
SERVO_CENTER = 90
SERVO_MIN = 30                        # 2 deg inside the V2 linkage's mechanical stops (28..142)
SERVO_MAX = 140                       # so the servo never stalls against them
SERVO_TURN_LEFT = 45                  # SERVO_SHIFT_LEFT in the sketch
SERVO_TURN_RIGHT = 135                # SERVO_SHIFT_RIGHT

MAX_PWM = 100                         # hard speed cap, forward AND reverse (ESP32 caps it too)
BASE_SPEED = 90                       # PWM 0..255, straights. 90 measures 25.9 cm/s
TURN_SPEED = 90                       # PWM, forward part of a turn
REVERSE_SPEED = 90                    # PWM, reversing

# ---------------------------------------------------------------- open round logic
TOTAL_TURNS = 12                      # 3 laps x 4 corners
TURN_THRESHOLD_CM = 60.0              # front distance that triggers a corner
SIDE_GAP_THRESHOLD_CM = 50.0          # side farther than this = open corner
EMERGENCY_FRONT_CM = 40.0             # turn even without an open side
# Blind lock (no side is clearly open) is how the FIRST corner can pick the
# wrong lap direction and take the whole race with it. One frame of L37/R42 -
# five centimetres, well inside ToF noise, and a pillar near a wall shortens
# that side anyway - is not evidence. Require a real gap, held steady.
LOCK_MIN_MARGIN_CM = 15.0             # one side must beat the other by this
LOCK_CONFIRM_FRAMES = 12              # ...for this many consecutive frames
TURN_COOLDOWN_S = 1.0                 # straight time after a turn
TURN_DONE_ERR_DEG = 13.0               # turn ends when heading error < this
TURN_TIMEOUT_S = 6.5                  # ...or after this long
FINISH_TIME_S = 3.0                   # drive on after turn 12 to reach the start section

REVERSE_START_CM = 12.0               # wedged: reverse below this...
REVERSE_STOP_CM = 20.0                # ...until the front is clear again

# Hard override: this close to something ahead, TURN. No side-gap check, no
# cooldown, no waiting for a clean read - the car is about to hit a wall and
# nothing else matters. The ONLY thing that suppresses it is an actual dodge
# already in progress, where the front sensor is looking at the pillar rather
# than at a wall.
FRONT_FORCE_TURN_CM = 48.0            # fallback; live value is params["front_turn_cm"]

# Corner turns are PROPORTIONAL, not a fixed lock: the steering follows the
# heading still to be turned, so the car goes in hard at the start and eases
# out as it comes round, instead of holding full lock to the last degree and
# scrubbing. corner_steer_deg is the CAP, reached only while the error is
# large. Starting earlier (front_turn_cm) with a smaller cap is what makes a
# turn smooth: the same 90 degrees spread over more ground.
CORNER_KP = 0.55                      # servo deg off centre per deg of heading error
CORNER_MIN_OFF_DEG = 7.0              # ...never less than this, or the turn stalls

# Dodging a pillar first seen FAR away should be gentler and longer, not the
# same sharp flick used when it is close: the car has room, so it can lean out
# over a longer distance. Scale = trigger distance / distance at commit,
# clamped - a pillar committed at twice the trigger distance gets roughly half
# the steering angle held over a longer leg.
DODGE_FAR_STEER_MIN = 0.55            # gentlest the angle may be scaled to
DODGE_FAR_LEG_MAX = 1.7               # longest the legs may be stretched to
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

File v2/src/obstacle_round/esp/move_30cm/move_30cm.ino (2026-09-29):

/*
 * ============================================================================
 *  WRO 2026 Future Engineers - Team Yo_Error_404
 *  move_30cm - ESP32-C3 Super Mini (V2 bot) - encoder distance test
 * ============================================================================
 *
 *  WHAT IT DOES
 *    Press START. The car drives straight forward until the wheel encoder has
 *    counted 30 cm, then stops. That is all. No ToF, no BNO055, no camera, no
 *    obstacle logic, no turns.
 *
 *  Ported from the classic-ESP32 loop sketch (2500 mm -> 90 deg turn x12):
 *  the encoder maths and the 90 ticks/metre calibration are kept, everything
 *  else is stripped out and the pins/motor driver are changed to the V2 bot.
 *
 *  PATCH NOTES
 *    PATCH 1  (2026-09-21)  First version. Pins moved from the classic ESP32
 *             (IN1 27 / IN2 26 / ENA 14 / servo 13 / encoder 18,19 / btn 15)
 *             to the ESP32-C3 Super Mini V2 pinout. Motor driver changed from
 *             the L298-style IN1+IN2+ENA to the MD10112's PWM+DIR pair, which
 *             is how open_slave.ino drives this car. Encoder moved OFF GPIO18/
 *             19 - see the warning below. Added a hard timeout so the car can
 *             never run away if the encoder is silent.
 *    PATCH 2  (2026-09-21)  Removed the NeoPixel strip - this car does not have
 *             one. Status is reported over serial only. GPIO7 is now free.
 *    PATCH 3  (2026-09-21)  Encoder moved to GPIO4 (A) and GPIO5 (B) - proved
 *             on the bench with encoder_probe, not guessed. Motor pins are now
 *             driven LOW as the very FIRST thing in setup(), before serial or
 *             anything else: encoder_probe left IN1 as INPUT_PULLUP, the
 *             MD10112 read that HIGH as 100% duty and the car ran away at full
 *             speed. A pin that commands the motor is never left an input.
 *    PATCH 4  (2026-09-21)  Servo spun continuously on boot. PATCH 3 had moved
 *             driveMotor(0) - an analogWrite - ahead of the servo attach, and
 *             on ESP32 core 3.x analogWrite claims an LEDC timer at ~1 kHz.
 *             ESP32Servo then shared that timer instead of getting a clean
 *             50 Hz one, so the servo saw nonsense pulse widths and ran away.
 *             Order now matches open_slave.ino, which is known good: the motor
 *             pins are still made safe first, but with digitalWrite LOW only
 *             (no LEDC involved), the servo attaches next and claims its 50 Hz
 *             timer, and analogWrite is not called until after that.
 *    PATCH 5  (2026-09-21)  Pressing START produced no reaction and no serial
 *             output at all, so there was no way to tell whether the button,
 *             the encoder or the motor was at fault. Added a 2 Hz heartbeat
 *             that prints the raw START pin level and the live tick count, so
 *             the board is never silent again. Drive speed raised 120 -> 150:
 *             120 PWM may simply be below the stall torque of this drivetrain.
 *    PATCH 6  (2026-09-21)  "Nothing moves when I press START" - because the
 *             run had ALREADY completed (29 ticks vs the 27 target) and DONE
 *             was a dead end: the button was only ever read in WAITING, so the
 *             sketch could run exactly once per power cycle. The button is now
 *             read in every state - a press in DONE re-arms for another run,
 *             and a press while DRIVING is an emergency stop.
 *    PATCH 7  (2026-09-21)  Calibrated. run_5s_ticks measured 2913 ticks over
 *             ~1.1 m, so TICKS_PER_METER goes 90 -> 2648 and the 30 cm target
 *             goes 27 -> 794 ticks. The inherited 90 was from the old bot and
 *             ~29x too small, which is why the car twitched and stopped.
 *             Also: the encoder's signed position counts NEGATIVE when driving
 *             forward on this car, so direction logic must not assume +ve is
 *             forward. This sketch uses labs() and is unaffected.
 *             NOTE: 1.1 m was a rough tape measurement, and the run includes
 *             ramp-up and coast, so treat 2648 as a first cut - re-measure
 *             over a longer distance if 30 cm comes out off.
 *    PATCH 8  (2026-09-21)  It came out off: 794 ticks measured 27 cm on the
 *             floor, 10% short. Recalibrated from that real result instead of
 *             the eyeballed 1.1 m - 794 / 0.27 = 2941 ticks/m, so the target
 *             becomes 882 ticks. This figure is measured over the actual 30 cm
 *             move, so it also folds in the ramp-up and the coast after the
 *             motor cuts, which a long free run does not represent.
 *    PATCH 9  (2026-09-21)  882 ticks measured 29 cm - 1 cm short. Scaled once
 *             more: 882 / 0.29 = 3041 ticks/m, target 912 ticks. Convergence
 *             so far: 794->27 cm, 882->29 cm, 912->30 cm expected. Note 1 cm
 *             is close to tape-measure and coast-variation noise, so chasing
 *             it further has limited value - coast distance also shifts with
 *             battery charge, which no fixed tick target can compensate for.
 *
 *  !! ENCODER PIN WARNING !!
 *    On the ESP32-C3, GPIO18 and GPIO19 ARE the native USB D-/D+ lines. They
 *    are what the Pi talks to this board over. Wiring the encoder there kills
 *    the USB link and the board can no longer be flashed or read normally, so
 *    the encoder CANNOT stay on 18/19 the way it was on the classic ESP32.
 *    The encoder on this car is on GPIO4 (A) and GPIO5 (B). That was measured
 *    with the encoder_probe sketch, which counted edges on every pin while the
 *    wheels turned - 4 and 5 were the only two that moved.
 *
 *  SAFETY
 *    Speed is capped at 170 PWM (team hard limit). The run also aborts after
 *    RUN_TIMEOUT_MS even if no ticks ever arrive, so a disconnected encoder
 *    stops the car instead of letting it drive off.
 *
 *  UPLOAD
 *    arduino-cli compile --upload -p <port> \
 *      --fqbn esp32:esp32:esp32c3:CDCOnBoot=cdc esp/move_30cm
 *    Libraries: ESP32Servo
 *
 *  NOTE: flashing this REPLACES open_slave.ino on the board. Reflash
 *  esp/open_slave/open_slave.ino.merged.bin to put the robot back to normal.
 * ============================================================================
 */

#include <Arduino.h>
#include <ESP32Servo.h>

// ---------------------------------------------------------------- pins (V2 bot, ESP32-C3)
#define IN1_PIN 1    // MD10112 PWM
#define IN2_PIN 0

// Direction polarity: LOW = forward on this car. Verified by tick sign -
// positive ticks have always meant forward, so +speed must produce them.
#define MOTOR_FORWARD_LEVEL LOW
#define MOTOR_REVERSE_LEVEL HIGH    // MD10112 DIR (HIGH = forward)
#define SERVO_PIN      6
#define START_BTN_PIN 10    // to GND, internal pull-up
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

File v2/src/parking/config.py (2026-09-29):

"""
parking/config.py - Tunable constants for standalone parking exit.
Team Yo_Error_404 - WRO 2026 Future Engineers (V2 Bot)
"""

# Hardware limits (calibrated from live vehicle)
SERVO_CENTER = 87            # True straight ahead is 87, not 90 (-3 deg trim)
SERVO_MIN = 30               # 2 deg inside mechanical stop (28)
SERVO_MAX = 140              # 2 deg inside mechanical stop (142)
MAX_PWM = 110                # Team cap on motor speed
TICKS_PER_CM = 20.78         # 2078 ticks/m, measured

# Networking & Hub
HUB_PORT = 5005              # UDP relay port used by dashboard.py
TELEMETRY_MAX_AGE_S = 0.5    # Freshness limit for telemetry
LOG_DIR = "/home/pi/parking/logs"

def load_params():
    return {}

# Parking exit tuning
EXIT_SPEED = 75              # Motor PWM during parking exit (out of 255)
STEER_LOCK_DEG = 50          # Increased turn lock (87+50=137 Right, 87-50=37 Left, safely within [30, 140])

TURN_OUT_CM = 25.0           # Stage 1: distance of initial turn-out arc (cm)
STRAIGHT_CM = 55.0           # Stage 2: forward displacement across lane (55 cm)
TURN_IN_CM = 25.0            # Stage 3: distance of turn-back arc (cm)
FORWARD_CM = 20.0            # Stage 4: final forward alignment run (20 cm)

HOLD_KP = 1.5                # Proportional gain for heading hold
STAGE_TIMEOUT_S = 14.0       # Failsafe stage timeout in seconds

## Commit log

2026-06-11 Initial commit: Open round firmware, electrical schematics, 3D CAD models, and team documentation
    [Chassis_bottom_view.stl, Chassis_top_view.stl, Ultrasonic_Sensor_Mount.stl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]
2026-06-11 Docs: power distribution board decision and bench test
2026-06-11 Docs: battery chemistry decision and placement testing
2026-06-18 Docs: camera choice, Pi camera over a USB webcam
2026-06-20 Commit 2: obstacle round schematic, Pi camera mount assembly, first testing video, Pi-ESP32 comm test + HSV tuner
    [pi_camera_3_mount.stl, pi_camera_3_mount_2.stl, pi_camera_3_mount_3.stl]
2026-06-22 Docs: switch to the Raspberry Pi 5 and Camera Module 3
2026-07-11 Docs: USB serial link between the Pi and the ESP32
2026-07-12 Commit 3: finished obstacle round code - ESP32 firmware, Raspberry Pi vision and navigation code, and README
2026-07-20 Docs: Pi camera and operating system reliability testing
2026-08-05 Commit 5: main README with overview, repository structure, team, hardware, mobility, power, sensor and software sections; team photo with logo; hardware lists synced into src READMEs
2026-08-12 Add rendered previews of the 3D printed parts
    Generated a PNG preview straight from each STL so the printed parts can be
    seen without opening a slicer, and referenced them from the models README.
    Also fixed two broken links in models/README.md (Drive_Shaft.stl and
    Drive_Motor_Holder.stl were capitalised and did not match the files on disk),
    added the chassis plate dimensions, and wrote up what the drive shaft coupler
    actually is: a double-D socket for the BO motor shaft at one end and a bore
    for the carbon fibre rod at the other.
2026-08-12 Add ESP32 pin map and system block diagram
    Two diagrams that were missing from schemes/: a colour-coded pin map of the
    ESP32 DevKit V1 showing which GPIO every subsystem lands on, and a block
    diagram of the whole vehicle split into power, sensing, control, computer
    vision and motion.
2026-08-12 Add software architecture and detection overlay images
    - Software building blocks diagram, showing how the ESP32 and Raspberry Pi
    stacks are layered and where the serial link crosses between them.
    - Four frames of the live annotated camera feed from an obstacle round test
    run, showing pillar detection, the zone lines and the navigation state.
    - Ackermann steering geometry diagram (Wikimedia Commons, CC BY-SA 3.0,
    attributed in the README).
2026-08-12 Rewrite the README as a full engineering write-up
    Restructured around a proper table of contents, closer to how a complete
    Future Engineers repository reads, and filled in the parts that were missing.
    New sections:
    - Design Process, pointing at the decision and testing logs.
    - Mobility Management, split into chassis, assembly, drivetrain, steering,
    wheels and printed parts, with the chassis plate dimensions and renders.
    - Assembly Instructions: the ten steps to build the car from printed parts,
    lower plate first.
    - 3D Printed Parts: why the drive shaft coupler took about 20 prints across
    5 designs, and what specifically kept going wrong with the tolerances.
    - Power and Sense Managemen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
2026-08-12 Replace the schematics with the new KiCad 10 sheets
    New open round and obstacle round schematics, committed as both a rendered
    PNG and the original PDF so the sheets can be zoomed or printed. The open
    round sheet is the ESP32 and everything hanging off it; the obstacle round
    sheet is the same circuit with the Raspberry Pi added.
    The new sheets document the power system properly for the first time, so
    the docs now match:
    - Two battery packs, not one. A 12V 3-cell main pack (BT2) feeding the
    distribution board, and a separate 7.4V 2-cell pack (BT1) that powers the
    steering servo alone, so a servo current spike cannot dip the logic rail.
    - Two power switches, one per pack (SW2, SW3), plus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
2026-08-12 Add the engineering journal and correct the docs against it
    Uploaded docs/Engineering_Journal.docx, the full journal submitted for the
    competition, and linked it from the Design Process section.
    Reading it back against the repository turned up several places where the
    READMEs did not match the vehicle, so those are fixed here:
    - Drive motor. There is one dual-shaft 100 RPM BO DC motor, not two motors:
    a shaft comes out of each side of the body and drives one rear wheel each
    through a printed coupler and a carbon fibre rod. This is also how we avoid
    a differential, which the rules forbid. Corrected everywhere, and added why
    100 RPM was chosen over a faster motor (the vision pipeline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
2026-08-12 Add the obstacle round video and the test data behind our decisions
    Every design choice in the trade-off section now carries the measurement
    that drove it, instead of only the reasoning.
    Videos: added the Obstacle Challenge test run, so there is now one video per
    challenge as the rules require.
    New trade-off sections, each with the numbers:
    - 100 RPM vs a faster motor. At 1.2 m/s a pillar at 30cm gives the vision
    pipeline ~7 frames to react; at 0.4 m/s it gives 22+. Avoidance success
    40% -> 86% over 50 test laps.
    - PLA vs PETG drive shafts. 8-12 acceleration cycles before cracking along
    the layer lines, versus 100+ cycles with no failures in PETG at 100% infill.
    - One battery domain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
2026-08-12 Add the bottom view of the vehicle
    Completes the photo set required by the rules: all four sides, the top and
    now the bottom. The underside shows the metal lower deck, the rear axle rods
    running out from the drive motor to each wheel, and the front steering
    linkage, none of which are visible from any other angle.
    The Vehicle Photos section of the README now shows top and bottom together,
    with the three remaining views below.
2026-09-15 Upload V2 codebase, CAD models, schematics, photos, and Engineering Journal PDF
    [Carbon_Rod_Differential_Coupler_V2.stl, Chassis_bottom_view.stl, Chassis_top_view.stl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]
2026-09-29 feat(v2): update v2/src with latest integrated codebase, parking modules, and specs
    [partitions.csv]
